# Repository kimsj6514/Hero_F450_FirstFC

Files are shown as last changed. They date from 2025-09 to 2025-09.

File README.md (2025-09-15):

# STM32F765 기반 커스텀 드론 비행 컨트롤러(FC) 개발

**현장 경험을 바탕으로 안정성과 신뢰성을 확보한 고성능 드론 FC를 직접 설계하고 개발하는 개인 프로젝트입니다.**

## 📖 프로젝트 소개
기성품 FC의 한계를 넘어, 특정 임무(정밀 비행, 안정적인 촬영 등)에 최적화된 드론을 개발하기 위해 시스템 아키텍처 설계부터 하드웨어 회로 설계, 펌웨어 개발까지 전 과정을 직접 수행합니다.

## ✨ 주요 기능
- [ ] IMU 센서(MPU-6050) 데이터 수신 및 처리
- [ ] Barometer 센서(BMP280)를 이용한 고도 추정
- [ ] PWM 신호를 이용한 BLDC 모터 제어
- [ ] (앞으로 개발할 기능들을 여기에 적어보세요)

## 🛠️ 기술 스택
- **MCU:** `STM32F765VI (ARM Cortex-M7)`
- **Language:** `C`, `C++`
- **Hardware Design:** `KiCad`
- **IDE:** `STM32CubeIDE`
- **Library:** `STM32 HAL Driver`

## 🏗️ 시스템 아키텍처
스크린샷 2025-09-14 171332

## 🔌 하드웨어 회로도
스크린샷 2025-09-14 170841

## 🚀 앞으로의 개발 계획
- [ ] FreeRTOS를 적용하여 멀티태스킹 환경 구축
- [ ] GPS 모듈을 연동하여 위치 기반 자율 비행 기능 구현
- [ ] PID 제어 알고리즘 튜닝을 통한 비행 안정성 향상

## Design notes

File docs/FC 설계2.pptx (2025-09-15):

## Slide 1

or

자이로, 가속도 센서

배터리 11.1 ~ 14.8V

DC/DC 5V

DC/DC 3.3V

MCU : STM32F767VIT6

3.3V

TX

조종 수신기

3.3V

TX

지자계센서

텔레메트리

SWD

3.3V

TX

기압계센서

GPSR

USB

TX

UART

I2C

ESC

Motor 1

ESC

Motor 2

ESC

Motor 3

ESC

Motor 4

PC

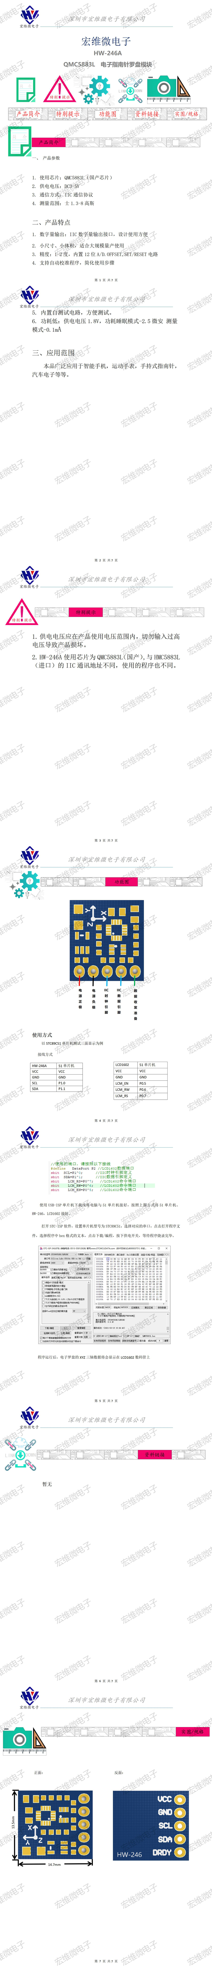
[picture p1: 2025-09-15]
datasheets/HW-246A QMC5883L/HW-246A产品说明书V0.0_01.jpg

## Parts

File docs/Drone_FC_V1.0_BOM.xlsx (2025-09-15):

no | Reference | Value | Qty | U/ Price | Amount | (Delivery) | Maker | Vendor | Remark
 | 510R(1.1kR)/1608 | R_Small_US | 1
 | BZ1 | Buzzer | 1
 | C1 | 470nF/1608 | 1
 | C2,C6,C7,C8,C10,C11,C12,C13,C14,C16 | 100nF/1608 | 10
 | C3,C5,C9 | 22uF/10V/TTB | 3
 | C4 | 2.2uF/1608 | 1
 | C15 | 220uF/10V/TTD | 1
 | D1 | R_LED/1608 | 1
 | D2,D8 | GLED/1608 | 2
 | D3,D4,D5 | BLED/1608 | 3
 | D6 | RLED/1608 | 1
 | D7 | YLED/1608 | 1
 | D9 | WLED/1608 | 1
 | FB1,FB2 | FerriteBead/2012 | 2
 | J1,J4 | Conn_01x04(2.54mm) | 2
 | J2 | Conn_01x02(2.54mm) | 1
 | J3 | Conn_01x02 | 1
 | J5 | LT_Conn_02x23_Odd_Even_2EA_Frame | 1 | $60000
 | J6 | Conn_02x02_Odd_Even | 2 | $720
 | J7,J8,J9,J10,J11 | Conn_01x03(2.54mm) | 5
 | Q1,Q2,Q3 | MMBT3904/SOT23 | 3
 | R1 | 1MR/1608 | 1
 | R2,R5,R6,R7,R8,R9,R10,R11 | 300R/1608 | 8
 | R3,R4 | 510R(1.1KR)/1608F | 2
 | R12,R13,R15,R16,R17,R21,R22,R23,R24,R25,R26 | 1kR/1608 | 11
 | R14 | 10kR/1608 | 1
 | R18,R20 | 910R/1608 | 2
 | R19,R27,R28 | 0R/1608 | 3
 | SW1 | LT_SW_Push/TS1101 | 1
 | SW2 | Slide_SW(MSL-1C2P) | 1 | $150
 | TP1,TP2 | TestPoint_Small | 2
 | U1 | AMS1117-3.3(SOT-223) | 1 | $180
 | U2 | Kia7805AF-5.0V | 5 | $5000
 | U3 | Hero_NEO-6M(GY-GPS6MV2)_module | 1 | $4500
 | U4 | Hero_MPU6050_module | 1 | $3000
 | U5 | GY-273_(HMC5883L)_module | 1 | $2500
 | U6 | Hero_LoRa_Ra-02 | 1 | $6000
 | U7 | Hero_BMP280_module | 1 | $2000
 |  | 충전기
 |  | XT60 커넥터 세트
 |  | 드론 교육용 세트 F450

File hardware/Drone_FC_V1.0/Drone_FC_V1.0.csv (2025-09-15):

Reference | Qty | Value | DNP | Exclude from BOM | Exclude from Board | Footprint | Datasheet
510R(1.1kR)/1608 | 1 | R_Small_US |  |  |  | Capacitor_SMD:C_0603_1608Metric_Pad1.08x0.95mm_HandSolder | ~
BZ1 | 1 | Buzzer |  |  |  | Buzzer_Beeper:Buzzer_12x9.5RM7.6 | ~
C1 | 1 | 470nF/1608 |  |  |  | Capacitor_SMD:C_0603_1608Metric_Pad1.08x0.95mm_HandSolder | ~
C2,C6,C7,C8,C10,C11,C12,C13,C14,C16 | 10 | 100nF/1608 |  |  |  | Capacitor_SMD:C_0603_1608Metric_Pad1.08x0.95mm_HandSolder | ~
C3,C5,C9 | 3 | 22uF/10V/TTB |  |  |  | Capacitor_Tantalum_SMD:CP_EIA-3528-21_Kemet-B_HandSolder | ~
C4 | 1 | 2.2uF/1608 |  |  |  | Capacitor_SMD:C_0603_1608Metric_Pad1.08x0.95mm_HandSolder | ~
C15 | 1 | 220uF/10V/TTD |  |  |  | Capacitor_Tantalum_SMD:CP_EIA-7343-31_Kemet-D_HandSolder | ~
D1 | 1 | R_LED/1608 |  |  |  | LED_SMD:LED_0603_1608Metric_Pad1.05x0.95mm_HandSolder | ~
D2,D8 | 2 | GLED/1608 |  |  |  | LED_SMD:LED_0603_1608Metric_Pad1.05x0.95mm_HandSolder | ~
D3,D4,D5 | 3 | BLED/1608 |  |  |  | LED_SMD:LED_0603_1608Metric_Pad1.05x0.95mm_HandSolder | ~
D6 | 1 | RLED/1608 |  |  |  | LED_SMD:LED_0603_1608Metric_Pad1.05x0.95mm_HandSolder | ~
D7 | 1 | YLED/1608 |  |  |  | LED_SMD:LED_0603_1608Metric_Pad1.05x0.95mm_HandSolder | ~
D9 | 1 | WLED/1608 |  |  |  | LED_SMD:LED_0603_1608Metric_Pad1.05x0.95mm_HandSolder | ~
FB1,FB2 | 2 | FerriteBead/2012 |  |  |  | Inductor_SMD:L_0805_2012Metric_Pad1.05x1.20mm_HandSolder | ~
J1,J4 | 2 | Conn_01x04(2.54mm) |  |  |  | Connector_PinHeader_2.54mm:PinHeader_1x04_P2.54mm_Vertical | ~
J2 | 1 | Conn_01x02(2.54mm) |  |  |  | Connector_PinHeader_2.54mm:PinHeader_1x02_P2.54mm_Vertical | ~
J3 | 1 | Conn_01x02 |  |  |  | Connector_PinHeader_2.54mm:PinHeader_1x02_P2.54mm_Vertical | ~
J5 | 1 | LT_Conn_02x23_Odd_Even_2EA_Frame |  |  |  | LT_Library80:LT_STM32F767VGT-23x2_Frame | ~
J6 | 1 | Conn_02x02_Odd_Even |  |  |  | Connector_PinHeader_2.54mm:PinHeader_2x02_P2.54mm_Vertical | ~
J7,J8,J9,J10,J11 | 5 | Conn_01x03(2.54mm) |  |  |  | Connector_PinHeader_2.54mm:PinHeader_1x03_P2.54mm_Vertical | ~
Q1,Q2,Q3 | 3 | MMBT3904/SOT23 |  |  |  | Package_TO_SOT_SMD:SOT-23 | https://ngspice.sourceforge.io/docs/ngspice-html-manual/manual.xhtml#cha_BJTs
R1 | 1 | 1MR/1608 |  |  |  | Resistor_SMD:R_0603_1608Metric_Pad0.98x0.95mm_HandSolder | ~
R2,R5,R6,R7,R8,R9,R10,R11 | 8 | 300R/1608 |  |  |  | Resistor_SMD:R_0603_1608Metric_Pad0.98x0.95mm_HandSolder | ~
R3,R4 | 2 | 510R(1.1KR)/1608F |  |  |  | Resistor_SMD:R_0603_1608Metric_Pad0.98x0.95mm_HandSolder | ~
R12,R13,R15,R16,R17,R21,R22,R23,R24,R25,R26 | 11 | 1kR/1608 |  |  |  | Resistor_SMD:R_0603_1608Metric_Pad0.98x0.95mm_HandSolder | ~
R14 | 1 | 10kR/1608 |  |  |  | Resistor_SMD:R_0603_1608Metric_Pad0.98x0.95mm_HandSolder | ~
R18,R20 | 2 | 910R/1608 |  |  |  | Resistor_SMD:R_0603_1608Metric_Pad0.98x0.95mm_HandSolder | ~
R19,R27,R28 | 3 | 0R/1608 |  |  |  | Resistor_SMD:R_0603_1608Metric_Pad0.98x0.95mm_HandSolder | ~
SW1 | 1 | LT_SW_Push/TS1101 |  |  |  | LT_Library80:LT_TS-1101_SW | ~
SW2 | 1 | Slide_SW(MSL-1C2P) |  |  |  | Button_Switch_THT:SW_Slide-03_Wuerth-WS-SLTV_10x2.5x6.4_P2.54mm | https://www.we-online.com/components/products/datasheet/450301014042.pdf
TP1,TP2 | 2 | TestPoint_Small |  |  |  | TestPoint:TestPoint_THTPad_D1.0mm_Drill0.5mm | ~
U1 | 1 | AMS1117-3.3(SOT-223) |  |  |  | Package_TO_SOT_SMD:SOT-223-3_TabPin2 | http://www.advanced-monolithic.com/pdf/ds1117.pdf
U2 | 1 | LT_LM340-5.0(SOT-223) |  |  |  | Package_TO_SOT_SMD:SOT-223-3_TabPin2 | http://www.diodes.com/datasheets/AP1117.pdf
U3 | 1 | Hero_NEO-6M(GY-GPS6MV2)_module |  |  |  | Hero_Footprint_25:Hero_GY-NEO6MV2 | ~
U4 | 1 | Hero_MPU6050_module |  |  |  | Hero_Footprint_25:Hero_MPU6050_1x08_P2.54mm_Vertical | ~
U5 | 1 | GY-273_(HMC5883L)_module |  |  |  | Hero_Footprint_25:Hero_gy273 | ~
U6 | 1 | Hero_LoRa_Ra-02 |  |  |  | Hero_Footprint_25:Hero_RoLa_Ra-02_1x08_P2.00mm_Vertical | ~
U7 | 1 | Hero_BMP280_module |  |  |  |  | ~

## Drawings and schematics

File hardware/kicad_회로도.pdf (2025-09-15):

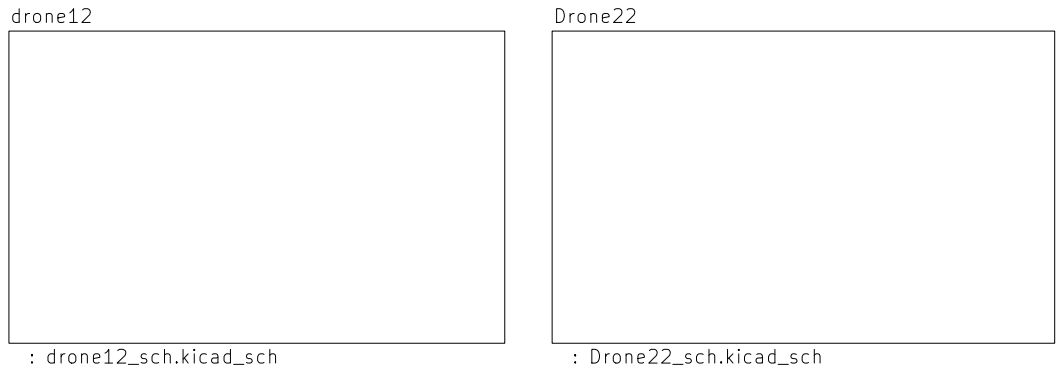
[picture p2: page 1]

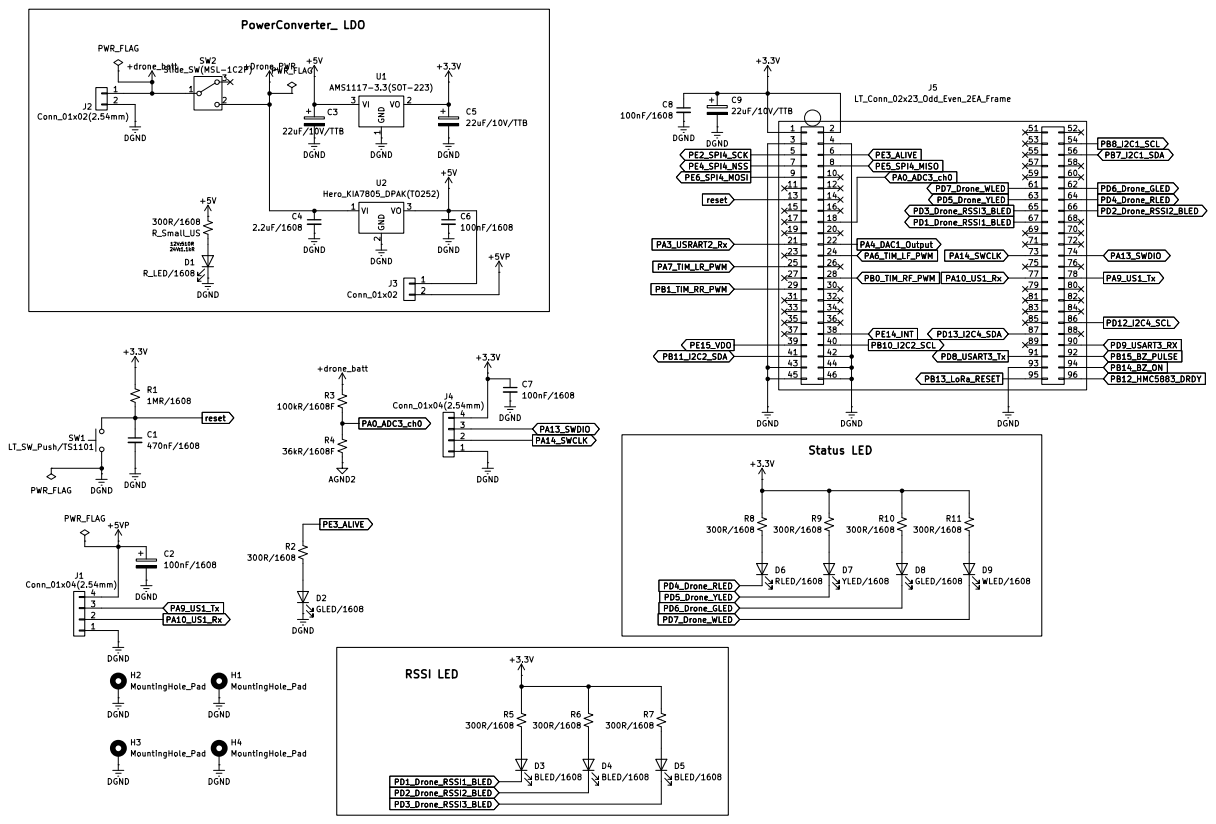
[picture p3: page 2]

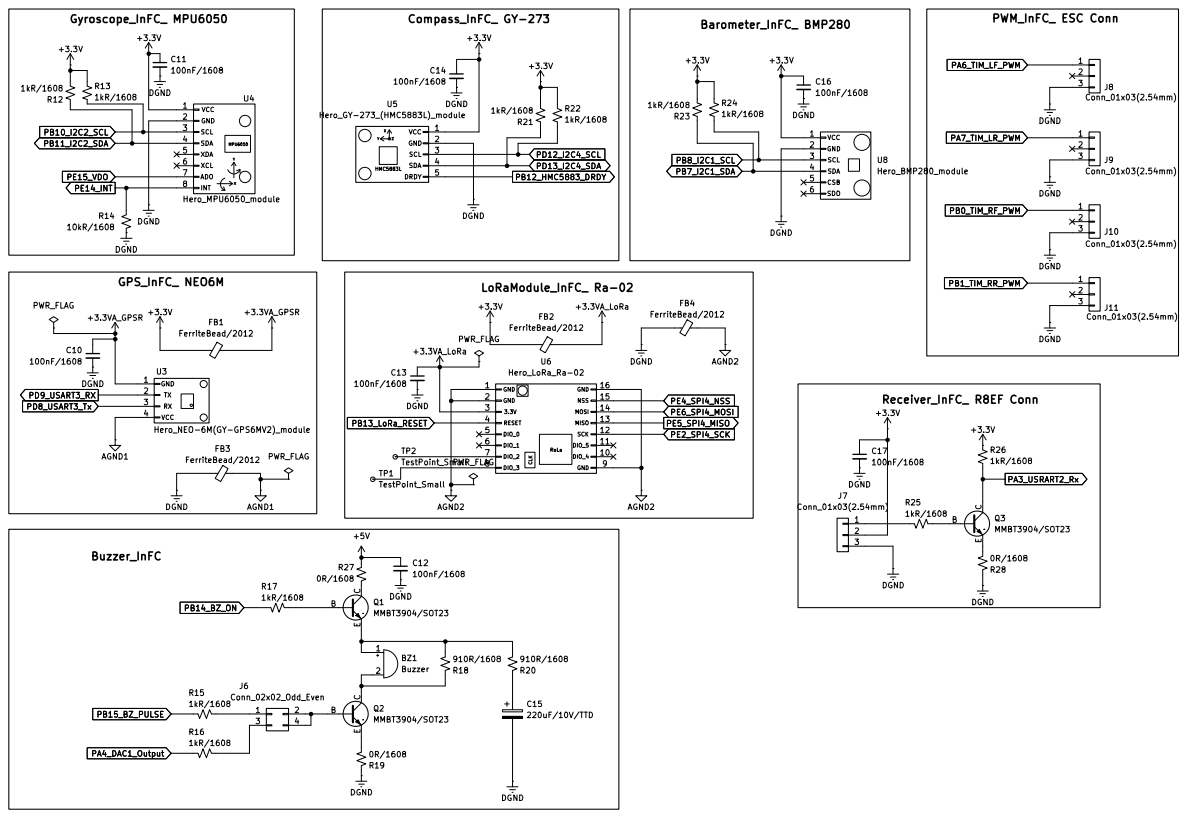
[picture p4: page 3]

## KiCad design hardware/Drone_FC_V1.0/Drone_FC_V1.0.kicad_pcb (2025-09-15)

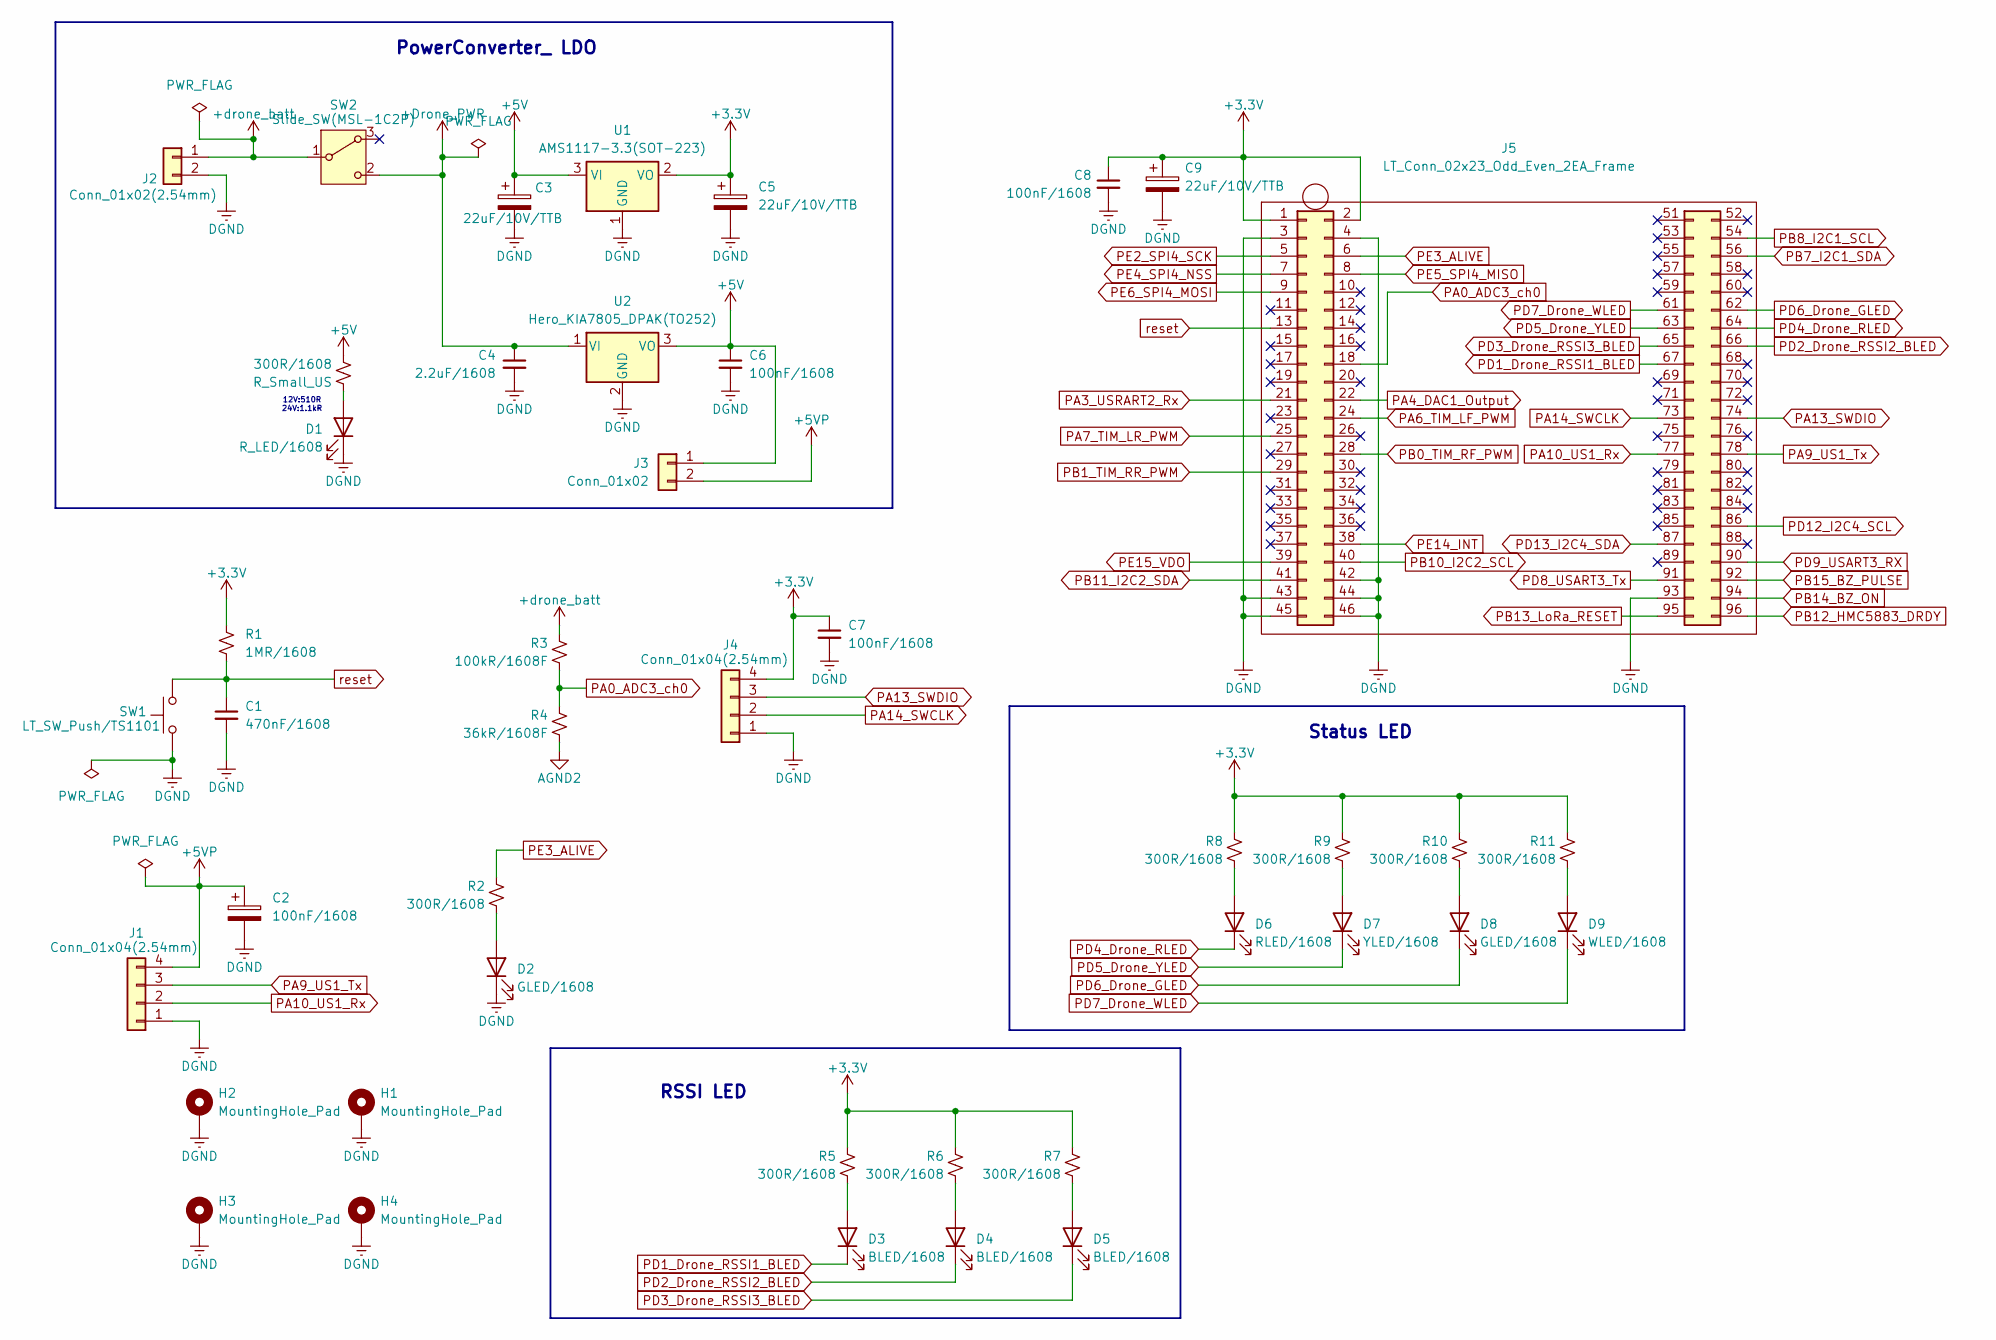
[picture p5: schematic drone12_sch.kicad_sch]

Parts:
300R/1608: R_Small_US; C_0603_1608Metric_Pad1.08x0.95mm_HandSolder
C1: 470nF/1608; C_0603_1608Metric_Pad1.08x0.95mm_HandSolder
C2, C6, C7, C8: 100nF/1608; C_0603_1608Metric_Pad1.08x0.95mm_HandSolder
C3, C5, C9: 22uF/10V/TTB; CP_EIA-3528-21_Kemet-B_HandSolder
C4: 2.2uF/1608; C_0603_1608Metric_Pad1.08x0.95mm_HandSolder
D1: R_LED/1608; LED_0603_1608Metric_Pad1.05x0.95mm_HandSolder
D2, D8: GLED/1608; LED_0603_1608Metric_Pad1.05x0.95mm_HandSolder
D3, D4, D5: BLED/1608; LED_0603_1608Metric_Pad1.05x0.95mm_HandSolder
D6: RLED/1608; LED_0603_1608Metric_Pad1.05x0.95mm_HandSolder
D7: YLED/1608; LED_0603_1608Metric_Pad1.05x0.95mm_HandSolder
D9: WLED/1608; LED_0603_1608Metric_Pad1.05x0.95mm_HandSolder
H1, H2, H3, H4: MountingHole_Pad; MountingHole_3.2mm_M3_Pad_TopBottom
J1, J4: Conn_01x04(2.54mm); PinHeader_1x04_P2.54mm_Vertical
J2: Conn_01x02(2.54mm); PinHeader_1x02_P2.54mm_Vertical
J3: Conn_01x02; PinHeader_1x02_P2.54mm_Vertical
J5: LT_Conn_02x23_Odd_Even_2EA_Frame; LT_STM32F767VGT-23x2_Frame
R1: 1MR/1608; R_0603_1608Metric_Pad0.98x0.95mm_HandSolder
R2, R5, R6, R7, R8, R9, R10, R11: 300R/1608; R_0603_1608Metric_Pad0.98x0.95mm_HandSolder
R3: 100kR/1608F; R_0603_1608Metric_Pad0.98x0.95mm_HandSolder
R4: 36kR/1608F; R_0603_1608Metric_Pad0.98x0.95mm_HandSolder
SW1: LT_SW_Push/TS1101; LT_TS-1101_SW
SW2: Slide_SW(MSL-1C2P); SW_Slide-03_Wuerth-WS-SLTV_10x2.5x6.4_P2.54mm
U1: AMS1117-3.3(SOT-223); SOT-223-3_TabPin2
U2: Hero_KIA7805_DPAK(TO252); TO-252-2

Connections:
+3.3V: C5.1, C7.1, C8.1, C9.1, J4.4, J5.1, J5.2, R1.1, R5.1, R6.1, R7.1, R8.1, R9.1, R10.1, R11.1, U1.2 (VO); also elsewhere on the board
+5V: 300R/1608.1, C3.1, C6.1, J3.1, U1.3 (VI), U2.3 (VO); also elsewhere on the board
+5VP: C2.1, J1.4, J3.2
+Drone_PWR: C4.1, SW2.2 (C), U2.1 (VI)
+drone_batt: J2.1, R3.1, SW2.1 (B)
AGND2: R4.2; also elsewhere on the board
DGND: C1.2, C2.2, C3.2, C4.2, C5.2, C6.2, C7.2, C8.2, C9.2, D1.1 (K), D2.1 (K), H1.1, H2.1, H3.1, H4.1, J1.1, J2.2, J4.1, J5.3, J5.4, J5.42, J5.43, J5.44, J5.45, J5.46, J5.93, SW1.1, U1.1 (GND), U2.2 (GND); also elsewhere on the board
unnamed: 300R/1608.2, D1.2 (A)
unnamed: D2.2 (A), R2.2
unnamed: D3.2 (A), R5.2
unnamed: D4.2 (A), R6.2
unnamed: D5.2 (A), R7.2
unnamed: D6.2 (A), R8.2
unnamed: D7.2 (A), R9.2
unnamed: D8.2 (A), R10.2
unnamed: D9.2 (A), R11.2
PA0_ADC3_ch0: J5.18, R3.2, R4.1
PA3_USRART2_Rx: J5.21; also elsewhere on the board
PA4_DAC1_Output: J5.22; also elsewhere on the board
PA6_TIM_LF_PWM: J5.24; also elsewhere on the board
PA7_TIM_LR_PWM: J5.25; also elsewhere on the board
PA9_US1_Tx: J1.3, J5.78
PA10_US1_Rx: J1.2, J5.77
PA13_SWDIO: J4.3, J5.74
PA14_SWCLK: J4.2, J5.73
PB0_TIM_RF_PWM: J5.28; also elsewhere on the board
PB1_TIM_RR_PWM: J5.29; also elsewhere on the board
PB7_I2C1_SDA: J5.56; also elsewhere on the board
PB8_I2C1_SCL: J5.54; also elsewhere on the board
PB10_I2C2_SCL: J5.40; also elsewhere on the board
PB11_I2C2_SDA: J5.41; also elsewhere on the board
PB12_HMC5883_DRDY: J5.96; also elsewhere on the board
PB13_LoRa_RESET: J5.95; also elsewhere on the board
PB14_BZ_ON: J5.94; also elsewhere on the board
PB15_BZ_PULSE: J5.92; also elsewhere on the board
PD1_Drone_RSSI1_BLED: D3.1 (K), J5.67 (Pin_17)
PD2_Drone_RSSI2_BLED: D4.1 (K), J5.66
PD3_Drone_RSSI3_BLED: D5.1 (K), J5.65
PD4_Drone_RLED: D6.1 (K), J5.64
PD5_Drone_YLED: D7.1 (K), J5.63
PD6_Drone_GLED: D8.1 (K), J5.62 (Pin_12)
PD7_Drone_WLED: D9.1 (K), J5.61
PD8_USART3_Tx: J5.91; also elsewhere on the board
PD9_USART3_RX: J5.90; also elsewhere on the board
PD12_I2C4_SCL: J5.86; also elsewhere on the board
PD13_I2C4_SDA: J5.87; also elsewhere on the board
PE2_SPI4_SCK: J5.5; also elsewhere on the board
PE3_ALIVE: J5.6, R2.1
PE4_SPI4_NSS: J5.7; also elsewhere on the board
PE5_SPI4_MISO: J5.8; also elsewhere on the board
PE6_SPI4_MOSI: J5.9; also elsewhere on the board
PE14_INT: J5.38; also elsewhere on the board
PE15_VDO: J5.39; also elsewhere on the board
reset: C1.1, J5.13, R1.2, SW1.2

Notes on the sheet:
RSSI LED
12V:510R 24V:1.1kR
PowerConverter_ LDO
Status LED

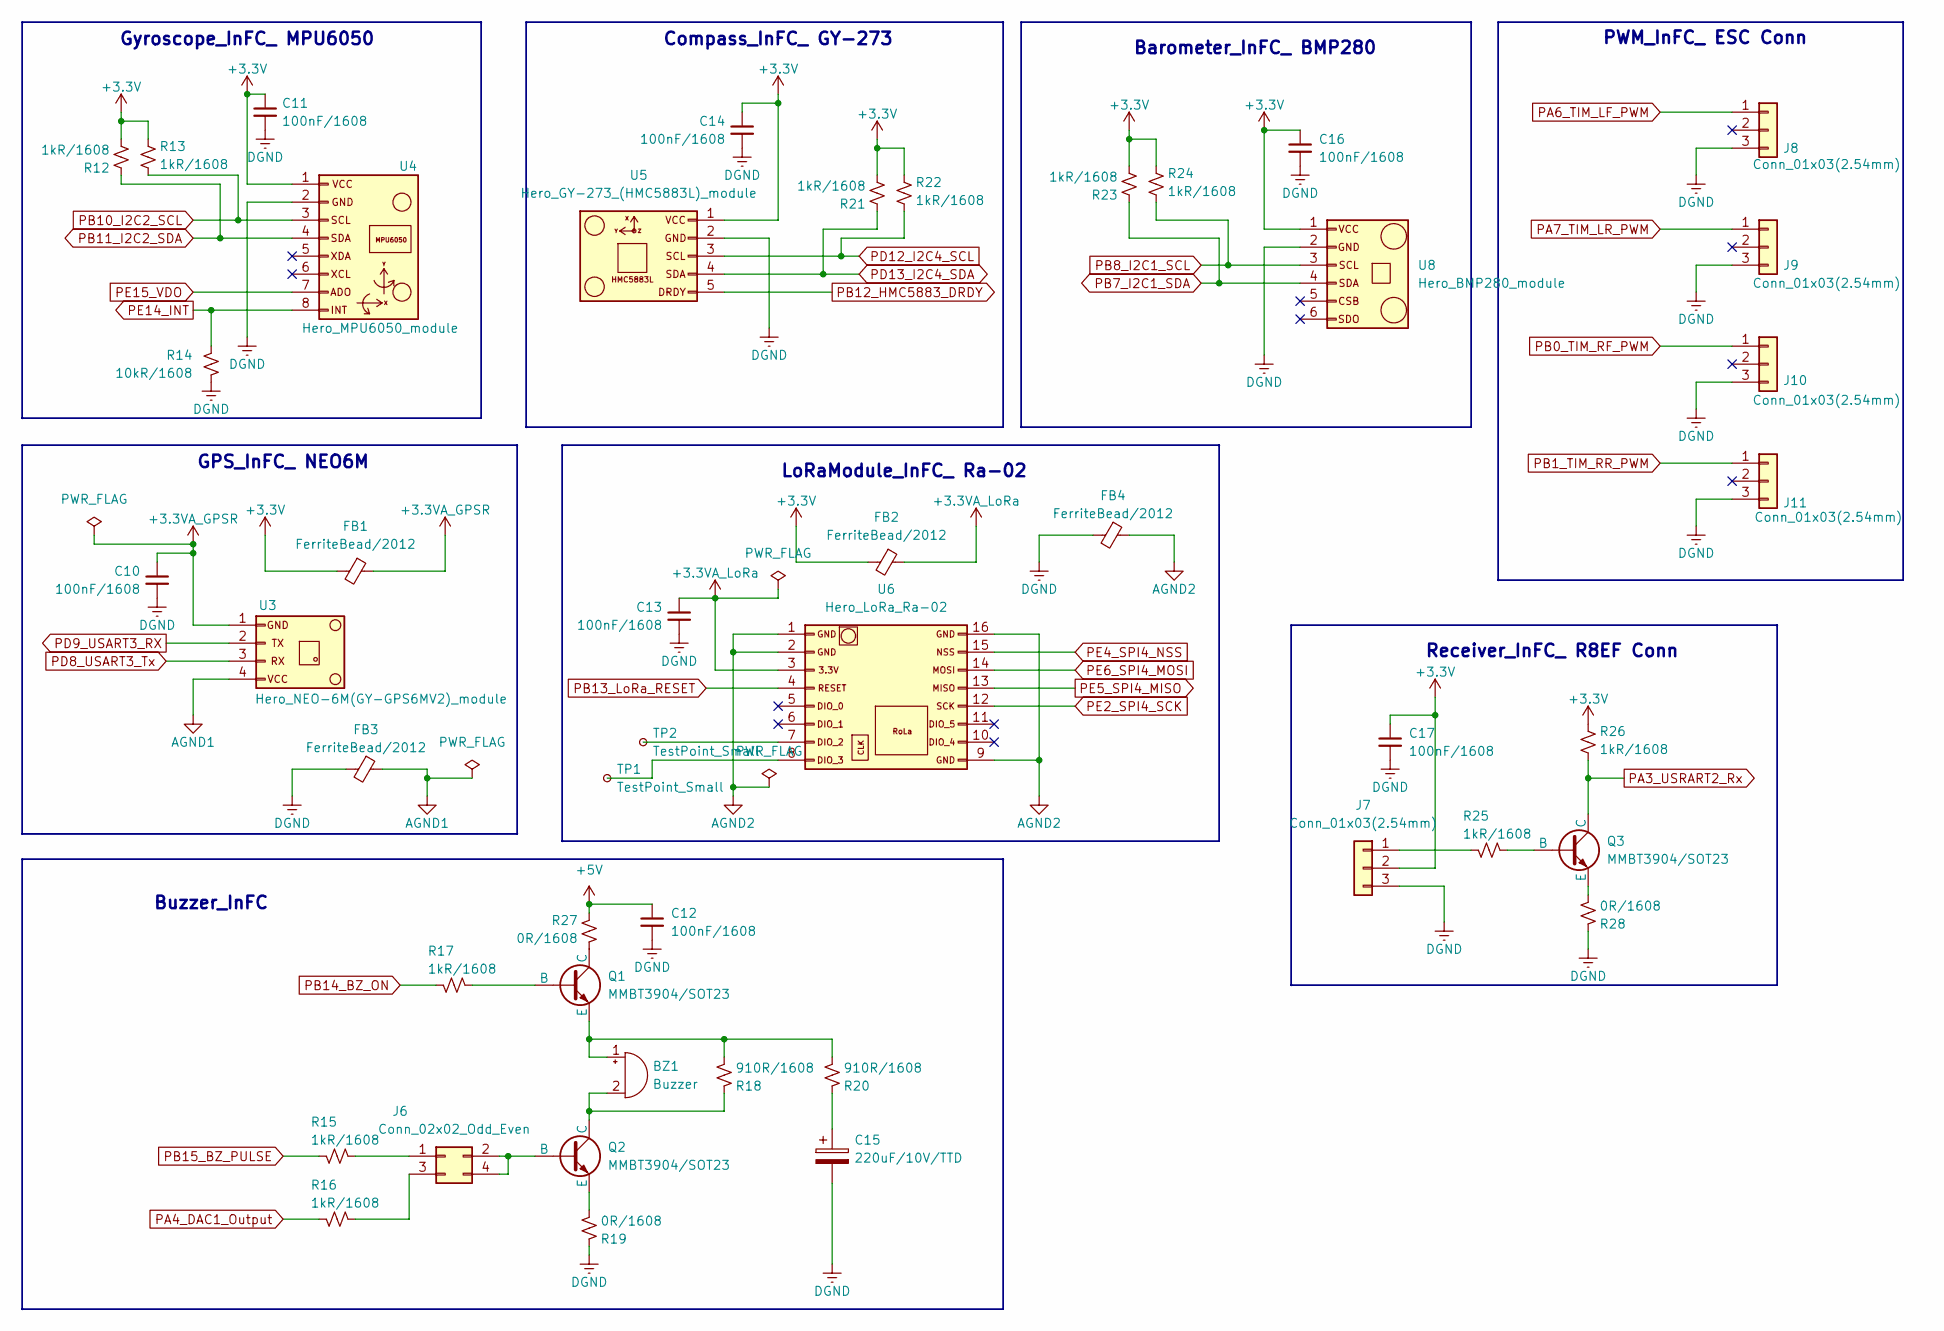
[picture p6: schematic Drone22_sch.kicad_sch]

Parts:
BZ1: Buzzer; Buzzer_12x9.5RM7.6
C10, C11, C12, C13, C14, C16, C17: 100nF/1608; C_0603_1608Metric_Pad1.08x0.95mm_HandSolder
C15: 220uF/10V/TTD; CP_EIA-7343-31_Kemet-D_HandSolder
FB1, FB2, FB3, FB4: FerriteBead/2012; L_0805_2012Metric_Pad1.05x1.20mm_HandSolder
J6: Conn_02x02_Odd_Even; PinHeader_2x02_P2.54mm_Vertical
J7, J8, J9, J10, J11: Conn_01x03(2.54mm); PinHeader_1x03_P2.54mm_Vertical
Q1, Q2, Q3: MMBT3904/SOT23; SOT-23
R12, R13, R15, R16, R17, R21, R22, R23, R24, R25, R26: 1kR/1608; R_0603_1608Metric_Pad0.98x0.95mm_HandSolder
R14: 10kR/1608; R_0603_1608Metric_Pad0.98x0.95mm_HandSolder
R18, R20: 910R/1608; R_0603_1608Metric_Pad0.98x0.95mm_HandSolder
R19, R27, R28: 0R/1608; R_0603_1608Metric_Pad0.98x0.95mm_HandSolder
TP1, TP2: TestPoint_Small; TestPoint_THTPad_D1.0mm_Drill0.5mm
U3: Hero_NEO-6M(GY-GPS6MV2)_module; Hero_GY-NEO6MV2
U4: Hero_MPU6050_module; Hero_MPU6050_1x08_P2.54mm_Vertical
U5: Hero_GY-273_(HMC5883L)_module; Hero_gy273
U6: Hero_LoRa_Ra-02; Hero_RoLa_Ra-02_1x08_P2.00mm_Vertical
U8: Hero_BMP280_module; Hero_BMP280_1x06_P2.54mm_Vertical

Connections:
+3.3V: C11.1, C14.1, C16.1, C17.1, FB1.2, FB2.2, J7.2, R12.2, R13.1, R21.2, R22.1, R23.2, R24.1, R26.1, U4.1, U5.1, U8.1; also elsewhere on the board
+3.3VA_GPSR: C10.1, FB1.1, U3.1
+3.3VA_LoRa: C13.1, FB2.1, U6.3
+5V: C12.1, R27.1; also elsewhere on the board
AGND1: FB3.1, U3.4
AGND2: FB4.1, U6.1, U6.2, U6.9, U6.16; also elsewhere on the board
DGND: C10.2, C11.2, C12.2, C13.2, C14.2, C15.2, C16.2, C17.2, FB3.2, FB4.2, J7.3, J8.3, J9.3, J10.3, J11.3, R14.2, R19.1, R28.1, U4.2, U5.2, U8.2; also elsewhere on the board
unnamed: BZ1.1 (+), Q1.3 (E), R18.2, R20.2
unnamed: BZ1.2 (-), Q2.1 (C), R18.1
unnamed: C15.1, R20.1
unnamed: J6.1, R15.1
unnamed: J6.2, J6.4, Q2.2 (B)
unnamed: J6.3, R16.1
unnamed: J7.1, R25.2
unnamed: Q1.2 (B), R17.1
unnamed: Q1.1 (C), R27.2
unnamed: Q2.3 (E), R19.2
unnamed: Q3.2 (B), R25.1
unnamed: Q3.3 (E), R28.2
unnamed: TP2.1, U6.7
unnamed: TP1.1, U6.8
PA3_USRART2_Rx: Q3.1 (C), R26.2; also elsewhere on the board
PA4_DAC1_Output: R16.2; also elsewhere on the board
PA6_TIM_LF_PWM: J8.1; also elsewhere on the board
PA7_TIM_LR_PWM: J9.1; also elsewhere on the board
PB0_TIM_RF_PWM: J10.1; also elsewhere on the board
PB1_TIM_RR_PWM: J11.1; also elsewhere on the board
PB7_I2C1_SDA: R23.1, U8.4; also elsewhere on the board
PB8_I2C1_SCL: R24.2, U8.3; also elsewhere on the board
PB10_I2C2_SCL: R13.2, U4.3; also elsewhere on the board
PB11_I2C2_SDA: R12.1, U4.4; also elsewhere on the board
PB12_HMC5883_DRDY: U5.5; also elsewhere on the board
PB13_LoRa_RESET: U6.4; also elsewhere on the board
PB14_BZ_ON: R17.2; also elsewhere on the board
PB15_BZ_PULSE: R15.2; also elsewhere on the board
PD8_USART3_Tx: U3.3; also elsewhere on the board
PD9_USART3_RX: U3.2; also elsewhere on the board
PD12_I2C4_SCL: R22.2, U5.3; also elsewhere on the board
PD13_I2C4_SDA: R21.1, U5.4; also elsewhere on the board
PE2_SPI4_SCK: U6.12; also elsewhere on the board
PE4_SPI4_NSS: U6.15; also elsewhere on the board
PE5_SPI4_MISO: U6.13; also elsewhere on the board
PE6_SPI4_MOSI: U6.14; also elsewhere on the board
PE14_INT: R14.1, U4.8; also elsewhere on the board
PE15_VDO: U4.7; also elsewhere on the board

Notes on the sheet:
LoRaModule_InFC_ Ra-02
Barometer_InFC_ BMP280
Buzzer_InFC
Receiver_InFC_ R8EF Conn
GPS_InFC_ NEO6M
Compass_InFC_ GY-273
PWM_InFC_ ESC Conn
Gyroscope_InFC_ MPU6050

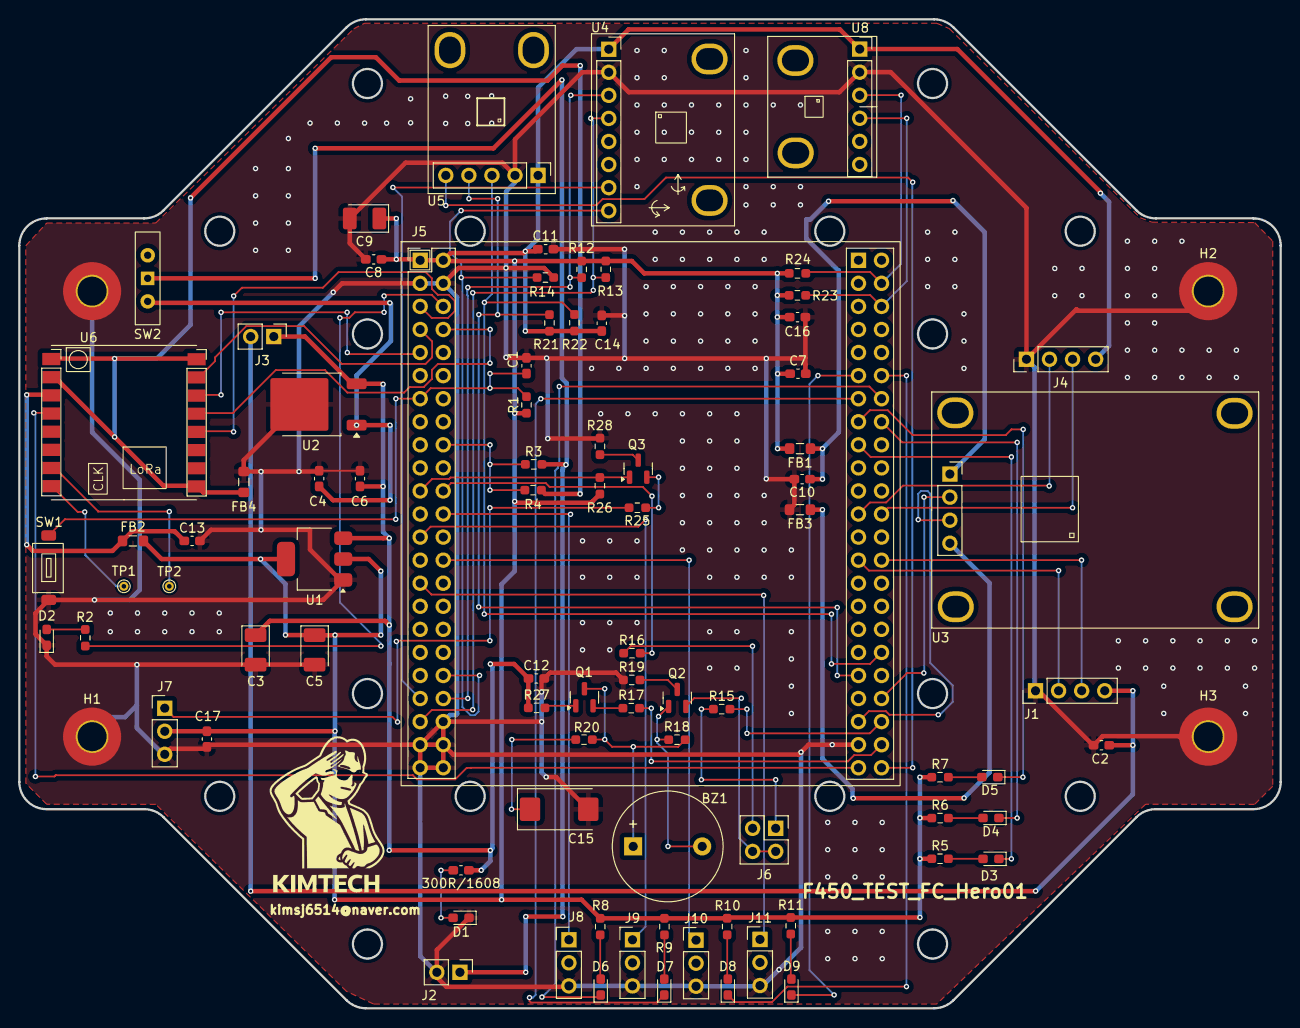
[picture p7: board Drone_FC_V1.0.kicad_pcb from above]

Board: 2 copper layers, 138.9 x 108.9 mm, 89 parts (0 on the bottom side), 71 nets.

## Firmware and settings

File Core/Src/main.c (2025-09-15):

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
/* Includes ------------------------------------------------------------------*/
#include "main.h"
#include "adc.h"
#include "dma.h"
#include "i2c.h"
#include "tim.h"
#include "usart.h"
#include "gpio.h"

/* USER CODE BEGIN Includes */
#include "stdio.h"
#include "ksj_led.h"
#include "ksj_rssi_led.h"
#include "ksj_sta_led.h"
#include "ksj_adc.h"
#include "ksj_booting.h"
#include "ksj_pwm.h"
#include "ksj_i2c.h"
#include "ksj_uart.h"
#include "D_motor.h"
#include "ksj_timer.h"
#include "D_joystick.h"
#include "ksj_mpu6050.h"
#include "d_global_defs.h"
/* USER CODE END Includes */


void SystemClock_Config(void);
static void MPU_Config(void);
/**
  * @brief  The application entry point.
  * @retval int
  */
int main(void)
{

  /* MPU Configuration--------------------------------------------------------*/
  MPU_Config();

  /* MCU Configuration--------------------------------------------------------*/

  /* Reset of all peripherals, Initializes the Flash interface and the Systick. */
  HAL_Init();

  /* Configure the system clock */
  SystemClock_Config();

  /* Initialize all configured peripherals */
  MX_GPIO_Init();
  MX_DMA_Init();
  MX_USART1_UART_Init();
  MX_ADC3_Init();
  MX_TIM3_Init();
  MX_I2C2_Init();
  /* USER CODE BEGIN 2 */
  //0. all led off
  all_led_off();
  // 1. for printf non buffering
  setvbuf(stdout, NULL, _IONBF, 0); //예외사항중 하나
  // for UART Rx Start
  HAL_UART_Receive_IT(&huart1, &rx_data1, 1); //예외사항으로 꼭 기억! UART에서 인터럽트방식을 사용하려면 꼭 이걸 넣어줘야 함
  //1. booting LED
  Power_on_led_running();
  //2. drone Init
  all_drone_peripheral_init();
  //3. ADC DMA Start
  HAL_ADC_Start_DMA(&hadc3, (uint32_t *)&adc_buf[0], ADC_BUF_LEN);
#if 0//--
  //4. TIM3 PWM Start
#if !defined PWM_DMA_MODE_EN
  HAL_TIM_PWM_Start(&htim3,TIM_CHANNEL_1);
#else
  // direction : memory to peripheral
  pa6_pwm_dma_run();
#endif
  //
#else//--
  //HAL_TIM_PWM_Start(&htim3,TIM_CHANNEL_1);
  //htim3.Instance->CCR1 = 140; //테스트용
  //htim3.Instance->CCR2 = 140;
  //htim3.Instance->CCR3 = 140;
  //htim3.Instance->CCR4 = 140;
  Motors_Init();
#endif//--

#if defined MPU6050_ENABLE
  // 5. MPU6050
  MPU6050_Initialization();
  mpu6050_offset_datas_get();
  //while(1); // block for normal operation.
#endif

  // 6. DWT 타이머 초기화 및 사이클 카운터 활성화/리셋
  DWT_Init();

  /* USER CODE END 2 */

  /* Infinite loop */
  /* USER CODE BEGIN WHILE */
  while (1)
  {
	  //
	  // 1. PE3 led
	  pe3_led_blinking_demo2();

	  // 2. printf
	  //printf("\r\nHello 2025.07.31");

	  // 3. PD1,2,3 RSSI LED
	  pd1_rssi_led1_blinking();
	  pd2_rssi_led2_blinking();
	  pd3_rssi_led3_blinking();

	  // 4. PD4,5,6,7 status LED
	  //ksj_sta_led_blinking();

	  // 5. ADC3
	  //adc_polling();
	  adc3ch0_demo_using_normal_DMA();

	  //6. pwm led with pa6
#if !defined PWM_DMA_MODE_EN
	  pa6_pwm_polling();
#else
	  // run with dma mode
#endif
	  //pa6_tim3_ch1_pwm_lf_motor_run1();
	  //data_pwm_process();
	  Motors_Update_PWM(); // 모터는 명령서(Keyboard_Input_Process();)에 따라 모터를 계속 업데이트

	  // 7. I2C2
	  //lt_eeprom_demo2();

	  // 8. command poser
	  //uart1_rx_process(); 이전 코드

	  //9. rcv data process
	#if defined __RX_CHAR_BUF_USE__
	  //Keyboard_Input_Process();
	  //rcv1_data_process();
	#elif defined __RX_STR_BUF_USE__
		  rcv2_str_process();
	#elif defined __RX_CMD_BUF_USE__
		  cmd2_exec_process();
	#endif
	  //10. D_joystick
	  Keyboard_Input_Process();


	  //11. mpu6050 test
	  //mpu6050_raw_datas_get();
	  //mpu6050_offset_reflect_datas_get(); //offset_reflect
	  //mpu6050_sensor_converted_demo();
	  //mpu6050_sensor_angle_demo();
	  mpu6050_sensor_cf_angle_demo();

    /* USER CODE END WHILE */

    /* USER CODE BEGIN 3 */
  }
  /* USER CODE END 3 */
}

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
 /* MPU Configuration */

void MPU_Config(void)
{
  MPU_Region_InitTypeDef MPU_InitStruct = {0};

  /* Disables the MPU */
  HAL_MPU_Disable();

  /** Initializes and configures the Region and the memory to be protected
  */
  MPU_InitStruct.Enable = MPU_REGION_ENABLE;
  MPU_InitStruct.Number = MPU_REGION_NUMBER0;
  MPU_InitStruct.BaseAddress = 0x0;
  MPU_InitStruct.Size = MPU_REGION_SIZE_4GB;
  MPU_InitStruct.SubRegionDisable = 0x87;
  MPU_InitStruct.TypeExtField = MPU_TEX_LEVEL0;
  MPU_InitStruct.AccessPermission = MPU_REGION_NO_ACCESS;
  MPU_InitStruct.DisableExec = MPU_INSTRUCTION_ACCESS_DISABLE;
  MPU_InitStruct.IsShareable = MPU_ACCESS_SHAREABLE;
  MPU_InitStruct.IsCacheable = MPU_ACCESS_NOT_CACHEABLE;
  MPU_InitStruct.IsBufferable = MPU_ACCESS_NOT_BUFFERABLE;

  HAL_MPU_ConfigRegion(&MPU_InitStruct);
  /* Enables the MPU */
  HAL_MPU_Enable(MPU_PRIVILEGED_DEFAULT);

}

/**
  * @brief  This function is executed in case of error occurrence.
  * @retval None
  */
void Error_Handler(void)
{
  /* USER CODE BEGIN Error_Handler_Debug */
  /* User can add his own implementation to report the HAL error return state */
  __disable_irq();
  while (1)
  {
  }
  /* USER CODE END Error_Handler_Debug */
}
#ifdef USE_FULL_ASSERT
/**
  * @brief  Reports the name of the source file and the source line number
  *         where the assert_param error has occurred.
  * @param  file: pointer to the source file name
  * @param  line: assert_param error line source number
  * @retval None
  */
void assert_failed(uint8_t *file, uint32_t line)
{
  /* USER CODE BEGIN 6 */
  /* User can add his own implementation to report the file name and line number,
     ex: printf("Wrong parameters value: file %s on line %d\r\n", file, line) */
  /* USER CODE END 6 */
}
#endif /* USE_FULL_ASSERT */

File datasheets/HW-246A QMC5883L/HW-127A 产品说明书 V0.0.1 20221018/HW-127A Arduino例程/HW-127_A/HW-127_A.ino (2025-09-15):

#include <Wire.h>           //使用IIC库
#define address 0x0D        //QMC5883L的设备地址设置

void setup(){
  Serial.begin(9600);  //初始化串口和I2C口
  Wire.begin();
//初始化模块
  Wire.beginTransmission(address);
  Wire.write(0x09); //选择控制寄存器0X09
  Wire.write(0x1D); //设置0x09寄存器为：OSR:512Hz，RNG：+/-8Gauss，ODG：200Hz，MODE：连续工作模式
  Wire.endTransmission();
}

void loop(){

  int x,y,z; //triple axis data

  Wire.beginTransmission(address);//读写开始
  Wire.write(0x00); //选择X,Y，Z所在数据储存寄存器
  Wire.endTransmission();

//读取X、Y、Z三个方向的坐标值
  Wire.requestFrom(address, 6);
  if(6<=Wire.available()){
    x = Wire.read()<<8; //X msb
    x |= Wire.read(); //X lsb
    z = Wire.read()<<8; //Z msb
    z |= Wire.read(); //Z lsb
    y = Wire.read()<<8; //Y msb
    y |= Wire.read(); //Y lsb
  }
//打印坐标到串口
  Serial.print("x: ");
  Serial.print(x);
  Serial.print("  y: ");
  Serial.print(y);
  Serial.print("  z: ");
  Serial.println(z);
  delay(100);
}

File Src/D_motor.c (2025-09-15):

/*
 * D_motor.c
 *
 *  Created on: Aug 26, 2025
 *      Author: kimsj
 */

#include "stdio.h"
#include "stdint.h"
#include "usart.h"
#include "tim.h"
#include "ksj_uart.h"
#include "D_motor.h"
#include "D_joystick.h"

#define PWM_MOTOR_MAX_DUTY 200
#define PWM_MOTOR_INTERVAL_DUTY 100
#define PWM_MOTOR_MIN_DUTY 100//1000//100


static ControlInput_t motor_controls = {0};

void Motors_Init(void)
{
	// 타이머의 기본 속도를 설정 (이 작업은 딱 한 번만 실행)
	htim3.Instance->PSC = 1080-1;

    HAL_TIM_PWM_Start(&htim3, TIM_CHANNEL_1);
    HAL_TIM_PWM_Start(&htim3, TIM_CHANNEL_2);
    HAL_TIM_PWM_Start(&htim3, TIM_CHANNEL_3);
    HAL_TIM_PWM_Start(&htim3, TIM_CHANNEL_4);

    htim3.Instance->CCR1 = 100;  // 1.0 ms
    htim3.Instance->CCR2 = 100;
    htim3.Instance->CCR3 = 100;
    htim3.Instance->CCR4 = 100;

    HAL_Delay(3000);  // 3초간 대기 → ESC 삑삑 하고 준비됨

}

void Motors_Set_Control_Input(ControlInput_t controls)
{
    // 조종실에서 보낸 새 명령서를 내부 서류함에 복사
    motor_controls = controls;
}

void Motors_Update_PWM(void)
{
    int16_t motor1_pwm = 0;
	int16_t motor2_pwm = 0;
	int16_t motor3_pwm = 0;
	int16_t motor4_pwm = 0;

    //  Quadcopter X-Type 믹싱 공식
    // 모터 번호: (2) (1)
    //          (3) (4)

    // 1단계: 모든 모터는 스로틀(기본 속도)에서 시작
    motor1_pwm = PWM_MOTOR_MIN_DUTY + motor_controls.throttle;
    motor2_pwm = PWM_MOTOR_MIN_DUTY + motor_controls.throttle;
    motor3_pwm = PWM_MOTOR_MIN_DUTY + motor_controls.throttle;
    motor4_pwm = PWM_MOTOR_MIN_DUTY + motor_controls.throttle;

    // 2단계: 피치(앞/뒤) 명령을 추가
    // 앞으로 가려면(-pitch), 앞쪽(1,2번) 모터는 느려지고, 뒤쪽(3,4번)은 빨라짐
    motor1_pwm = motor1_pwm - motor_controls.pitch;
    motor2_pwm = motor2_pwm - motor_controls.pitch;
    motor3_pwm = motor3_pwm + motor_controls.pitch;
    motor4_pwm = motor4_pwm + motor_controls.pitch;

    // 3단계: 롤(좌/우) 명령을 추가
    // 오른쪽으로 가려면(+roll), 오른쪽(1,4번) 모터는 느려지고, 왼쪽(2,3번)은 빨라짐
    // (※ 믹싱 공식은 FC 설정마다 +/-가 다를 수 있음.)
    motor1_pwm = motor1_pwm - motor_controls.roll;
    motor2_pwm = motor2_pwm + motor_controls.roll;
    motor3_pwm = motor3_pwm + motor_controls.roll;
    motor4_pwm = motor4_pwm - motor_controls.roll;

    // 4단계: 요(제자리 회전) 명령을 추가
    // 왼쪽으로 회전하려면(-yaw), 시계방향(2,4번) 모터는 느려지고, 반시계(1,3번)는 빨라짐
    motor1_pwm = motor1_pwm - motor_controls.yaw;
    motor2_pwm = motor2_pwm + motor_controls.yaw;
    motor3_pwm = motor3_pwm - motor_controls.yaw;
    motor4_pwm = motor4_pwm + motor_controls.yaw;

    // 최종 PWM 값이 100~200 범위를 벗어나지 않도록 안전하게 제한
    if (motor1_pwm < PWM_MOTOR_MIN_DUTY) motor1_pwm = PWM_MOTOR_MIN_DUTY;
    if (motor1_pwm > PWM_MOTOR_MAX_DUTY) motor1_pwm = PWM_MOTOR_MAX_DUTY;
    if (motor2_pwm < PWM_MOTOR_MIN_DUTY) motor2_pwm = PWM_MOTOR_MIN_DUTY;
    if (motor2_pwm > PWM_MOTOR_MAX_DUTY) motor2_pwm = PWM_MOTOR_MAX_DUTY;
    if (motor3_pwm < PWM_MOTOR_MIN_DUTY) motor3_pwm = PWM_MOTOR_MIN_DUTY;
    if (motor3_pwm > PWM_MOTOR_MAX_DUTY) motor3_pwm = PWM_MOTOR_MAX_DUTY;
    if (motor4_pwm < PWM_MOTOR_MIN_DUTY) motor4_pwm = PWM_MOTOR_MIN_DUTY;
    if (motor4_pwm > PWM_MOTOR_MAX_DUTY) motor4_pwm = PWM_MOTOR_MAX_DUTY;

    // 계산된 최종 값을 실제 타이머 하드웨어에 적용
    htim3.Instance->CCR3 = motor1_pwm; // 모터 1, RF
    htim3.Instance->CCR1 = motor2_pwm; // 모터 2, LF
    htim3.Instance->CCR2 = motor3_pwm; // 모터 3, LR
    htim3.Instance->CCR4 = motor4_pwm; // 모터 4, RR

}





/*void pa6_tim3_ch1_pwm_lf_motor_run1(void) //run1 : polling
{
	static uint8_t led_phase=0;
	static uint16_t i=0;
	static uint32_t pwm_period_time = 0;
	static uint8_t pwm_psc_init =0;

		if (pwm_psc_init ==0)
		{
			pwm_psc_init = 1;
			htim3.Instance->PSC = 1080-1;
		}

		if (HAL_GetTick() >= (pwm_period_time+10))
		{
			switch (led_phase)
			{
			case 0:
				htim3.Instance->CCR1 = PWM_MOTOR_MIN_DUTY + i++; //CCR = CH(채널)
				if (i>= PWM_MOTOR_INTERVAL_DUTY)	led_phase = 1;
				break;
			case 1:
				htim3.Instance->CCR1 = PWM_MOTOR_MIN_DUTY + i--;
				if (i == 0) led_phase = 0;
				break;
			}
			pwm_period_time = HAL_GetTick();
		}
}*/

/*void data_pwm_process(void)
{
	uint8_t data = 0;
	static uint8_t arrow_key = 0;
	static uint8_t key = 0;
	static uint8_t pwm_psc_init = 0;

	if (pwm_psc_init == 0)
	{
		pwm_psc_init = 1;
		htim3.Instance->PSC = 1080-1;
	}

	if(rcv1.wr_pos != rcv1.rd_pos)
	{
		data = rcv1.buf[rcv1.rd_pos];
		rcv1.rd_pos++;

		if(rcv1.rd_pos >= 10)
		rcv1.rd_pos = 0;

		switch(arrow_key)
		{
		case 0:
			if(data == 0x1b) // 1. 펏 번째 암호 'ESC' 문자인가?
			{
				arrow_key = 1;
			}
			break;


		case 1: //ESC를 받은 직후
			if(data == 0x5b) // 2. 두 번째 암호 '[' 문자인가?
			{
				arrow_key = 2; // 맞으면 마지막 암호를 기다리는 상태
			}
			else // 다른 문자가 들어오면 암호 실패, 평소 상태로 복귀.
			{
				arrow_key = 0;
			}
			break;

		case 2:
			if(data == 0x41) // 3. 위쪽'A' or 아래쪽'B' 화살표인가?
			{
				if (key < PWM_MOTOR_INTERVAL_DUTY)
				{
					key++;
				}
			}

			else if (data == 0x42)
			{
				if (key > 0)
				{
					key--;
				}
			}

			htim3.Instance->CCR1 = PWM_MOTOR_MIN_DUTY + key;
			printf("\r\nMotor Duty: %d", (int)htim3.Instance->CCR1) ;

			arrow_key = 0;// 암호 해독이 성공하든, 실패하든 원래대로 돌아간다.
			break;
		}
	}
}*/

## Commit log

2025-09-15 FC 펌웨어 프로젝트 초기 파일 추가
    [Drone22_sch.kicad_sch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]
2025-09-15 프로젝트 폴더 구조 정리
    [Drone22_sch.kicad_sch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]

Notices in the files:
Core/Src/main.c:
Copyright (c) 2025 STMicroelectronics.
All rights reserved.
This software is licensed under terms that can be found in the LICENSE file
